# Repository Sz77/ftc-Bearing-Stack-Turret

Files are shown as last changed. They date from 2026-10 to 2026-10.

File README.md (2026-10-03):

# Bearing Stack Turret with Vernier Encoder (BETA)

Designed by **Stefan** 
*Alum of FRC 5654 (Phoenix) | Mentor for FTC 12201 (TATOOINE)*

> **⚠️ STATUS: BETA & UNTESTED**
> I designed this setup for fun. It is currently in Beta and has not been fully tested yet. Feel free to copy, use, and learn from it, but please provide credit if you use or adapt this design!

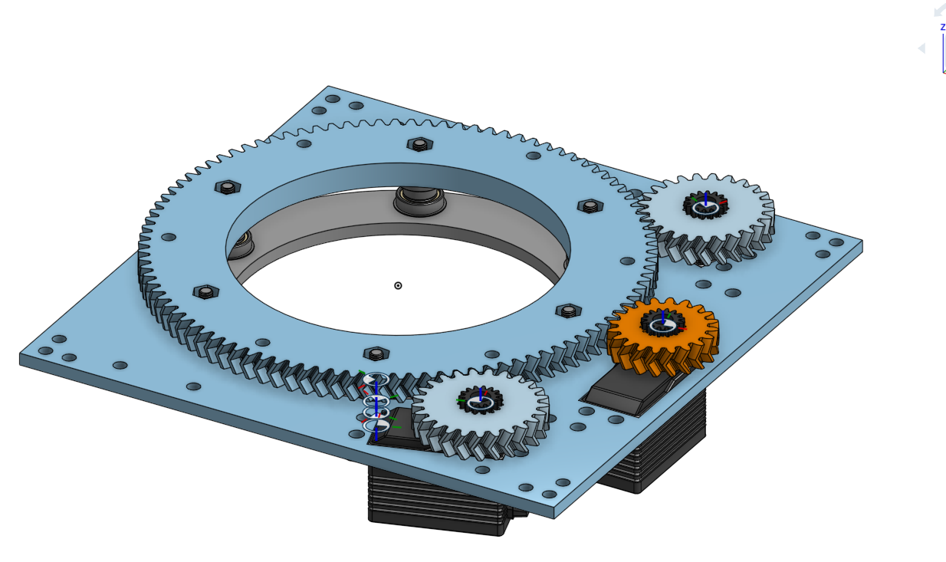
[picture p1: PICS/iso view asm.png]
Isometric View Assembly

*(TODO: Place a picture of the fully assembled physical turret here)*

## CAD & Files Availability
I will not publish the native CAD (at least not anytime soon). However, I do publish the **STLs, DXFs, and example code** here for you to use. Sometime in the future, I will publish the Onshape document.

### Repository Structure
* **`STL/`** - Contains all the 3D printable STL files (like the bearing adapters).
* **`DXF/`** - Contains the DXF files for machining/cutting the main plate and inner brace.
* **`code/`** - Contains the example code for reading the encoders and controlling the turret.
* **`PICS/`** - Reference images and CAD renders.

## Overview
This is a custom Bearing Stack Turret featuring a vernier encoder setup. 

**Top View:**
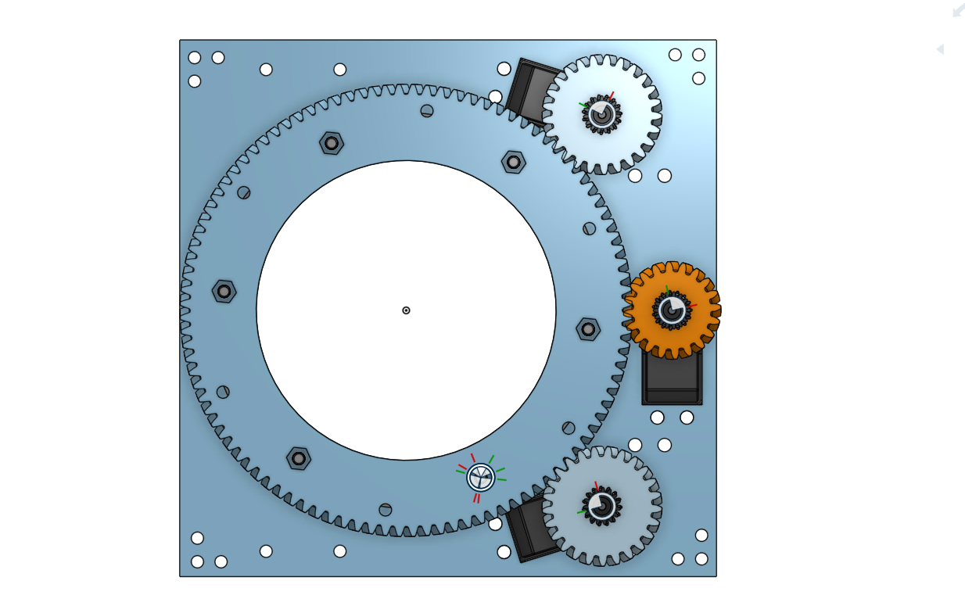
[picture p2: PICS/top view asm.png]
Turret Top View CAD


**Bottom View:**
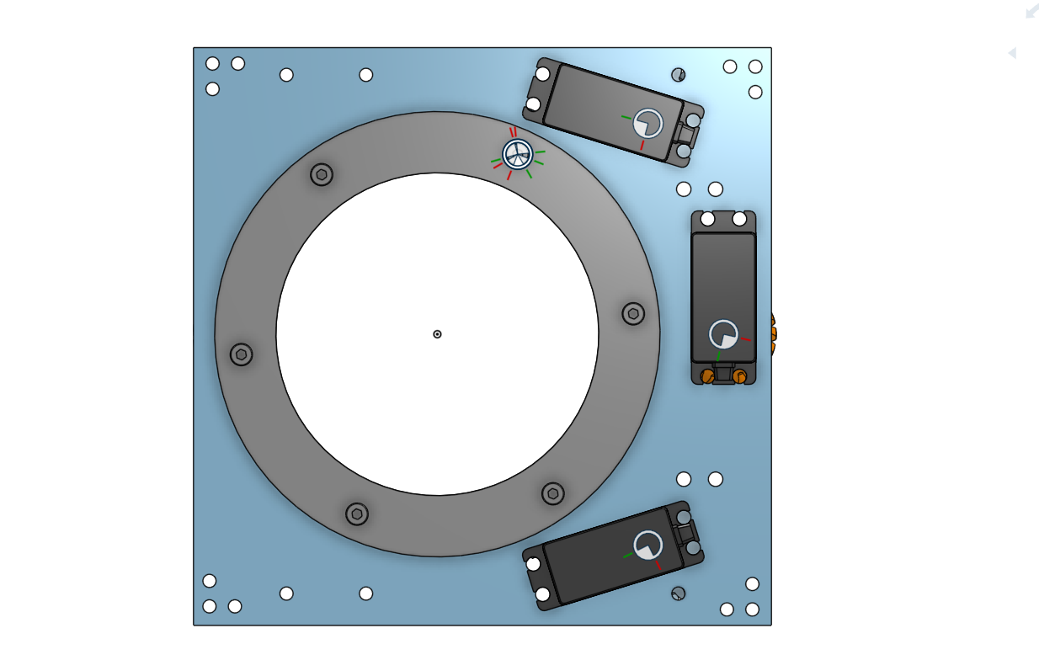
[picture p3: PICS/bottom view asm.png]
Turret Bottom View CAD


### How the Vernier Encoder Works
A vernier encoder setup uses two absolute encoders driven by gears with slightly different tooth counts—in this design, the motorized encoder A uses a 25-tooth gear and encoder B uses a 20-tooth gear, both interacting with the 100-tooth main gear. Because of the difference in tooth counts, the two encoders rotate at different speeds relative to each other as the main turret turns. By measuring the mathematical difference (or phase shift) between the readings of these two encoders, the software can calculate the exact absolute position of the main turret. This allows you to get highly precise, absolute positioning over multiple rotations without needing to mount a massive, expensive hollow-bore absolute encoder directly to the center of the turret.

---

## Bill of Materials (BOM) & Visual Part List

Below is a complete list of required parts with their CAD references. *(TODO: Add physical pictures of manufactured parts as they are made).*

### Electronics & Motors
* **1 or 2x Axon MINI Servos:** Used for turret rotation. With an Axon MINI, the max turret RPM is ~27.
  * *(TODO: Physical Part Image - Axon MINI)*
* **1x Axon MAX or Axon MINI (for Encoder B):** 
  * 🛑 **CRITICAL WARNING:** This is used *strictly* for its encoder. **DO NOT plug in the PWM cable.** Only plug in the analog sensor.
  * *(TODO: Physical Part Image - Axon MAX/MINI)*

### Gears
* **1x Main Gear:** 100 Teeth
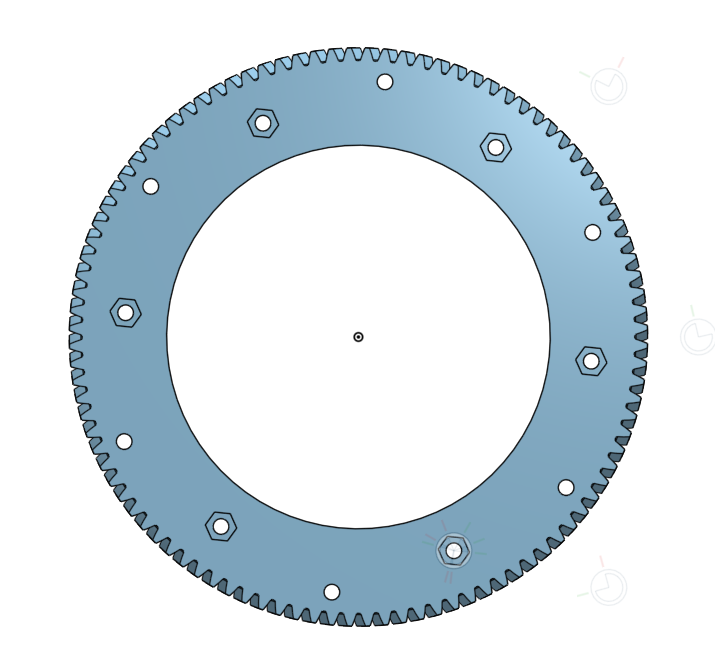
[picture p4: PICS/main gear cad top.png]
Main Gear CAD
  * 
* **1 or 2x Encoder A Gear (Motorized):** 25 Teeth 
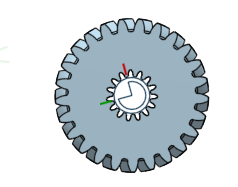
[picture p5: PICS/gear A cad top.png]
Gear A CAD
  * 
* **1x Encoder B Gear:** 20 Teeth
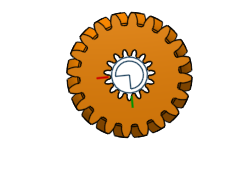
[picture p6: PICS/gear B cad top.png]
Gear B CAD
  * 
* **2 or 3x Servo Gears (15T Gear to 25T Spline):** 
  * *(TODO: CAD/Physical Image - Servo Gear)*
  * *Builder's Note:* My current printed version requires disassembling the servo and heat-pressing the adapter. This is bad and I don't recommend it. Instead, I highly recommend using COTS alternatives like **REV-41-1364-PK4** or **goBILDA 2305-0025-0015**.

### Bearing Stacks (Hardware)
You will need **6 bearing stacks** in total (4 will technically work, but 6 is highly recommended). 

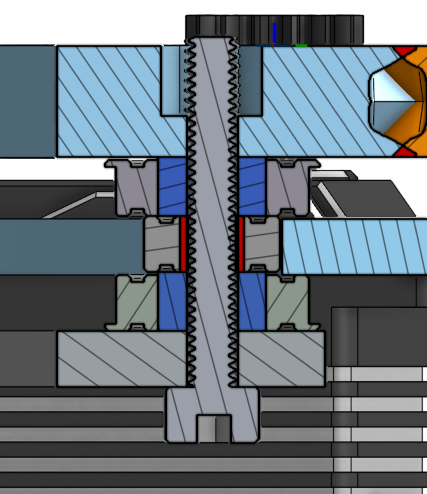
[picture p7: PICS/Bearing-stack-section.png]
Bearing Stack Section View


**For EACH of the 6 stacks, you need:**
* **2x Big Bearings:** Standard round goBILDA bearings.
* **2x Printed Adapters:** 4mm screw to 8mm goBILDA ID.
* **1x Small Bearing:** 4x10x4mm
* **1x M4 Screw & Nut:** Nylock nuts highly recommended.

### Structural Plates & Materials
* **Main Plate:** 6061 Aluminum is highly recommended. (Polycarbonate might work, but advised against).
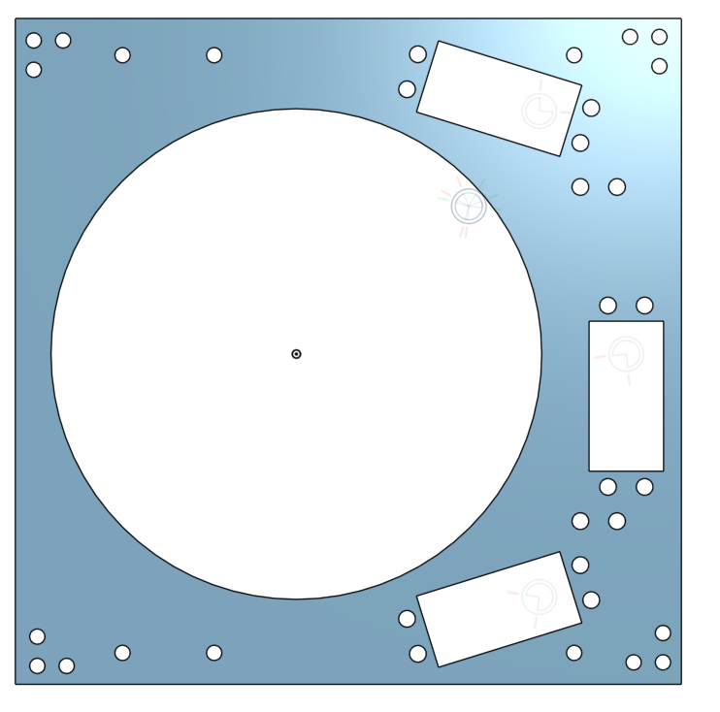
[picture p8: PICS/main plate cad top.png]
Main Plate CAD
  * 
* **Inner Brace:** Polycarbonate works well.
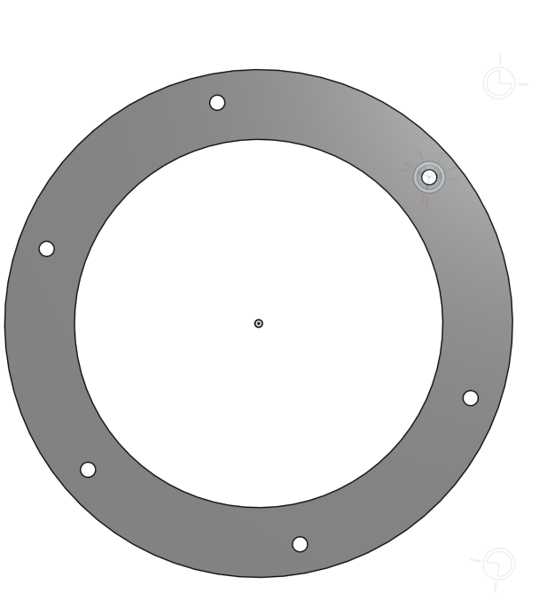
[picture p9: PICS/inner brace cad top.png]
Inner Brace CAD
  * 

---

## Assembly Guide

### Step-by-Step (Lego-Style) Instructions

**Step 1: Bearing Stack Pre-Assembly**
* Assemble the 6 bearing stacks using the big bearings, small bearing, printed adapters, and M4 hardware. Ensure Nylock nuts are secure but allow the bearings to spin freely.
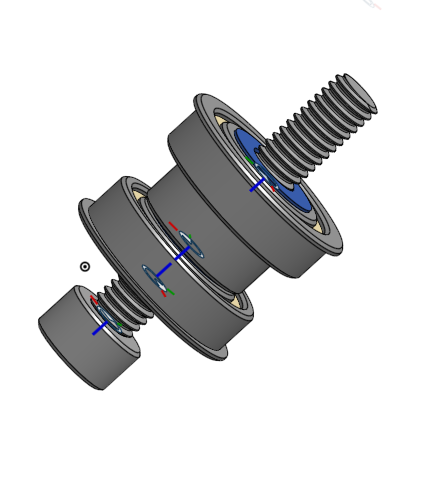
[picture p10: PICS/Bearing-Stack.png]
Bearing Stack
* 
* *(TODO: Physical assembly step picture)*

**Step 2: Installing Stacks to the Inner Brace**
* Mount the assembled bearing stacks onto the inner brace. 
* *(Reference `inner brace cad top.png` and `bottom view asm.png` for layout)*
* *(TODO: Physical assembly step picture)*

**Step 3: Main Plate & Gear Alignment**
* Sandwich the main 100T gear and fit the main plate over the bearing stacks. Double-check that the turret rotates smoothly without binding.
* *(Reference `iso view asm.png` for stacking order)*
* *(TODO: Physical assembly step picture)*

**Step 4: Servo & Vernier Encoder Mounting**
* Mount the 1 or 2 Axon MINIs (with 25T Gear A) and the passive Axon MAX/MINI (with 20T Gear B). 
* Carefully align the gear mesh before fully tightening the mounting screws to prevent stripping the teeth under load.
* *(Reference `top view asm.png` for gear positions)*
* *(TODO: Physical assembly step picture)*

**Step 5: Final Wiring & Verification**
* Route the servo cables. Remember to ONLY plug in the analog sensor cable for the Encoder B servo.
* *(TODO: Physical wiring/verification step picture)*

## License & Usage
Made for the robotics community. You are welcome to copy, use, and learn from this design. Please credit Stefan / FRC 5654 / FTC 12201 when sharing or implementing.

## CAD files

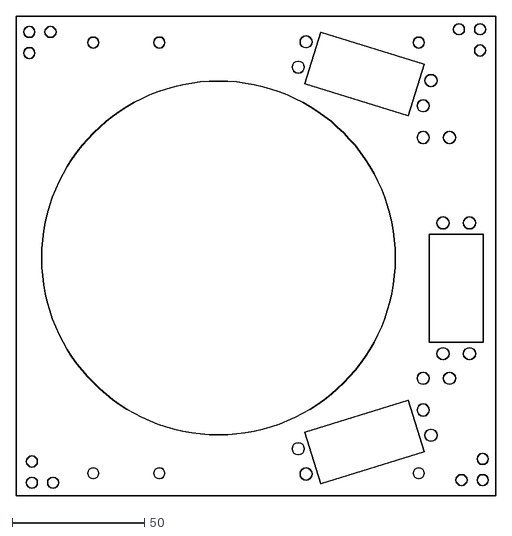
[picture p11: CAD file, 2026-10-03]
DXF/main plate-4mm-top.dxf
181.6 x 181.6

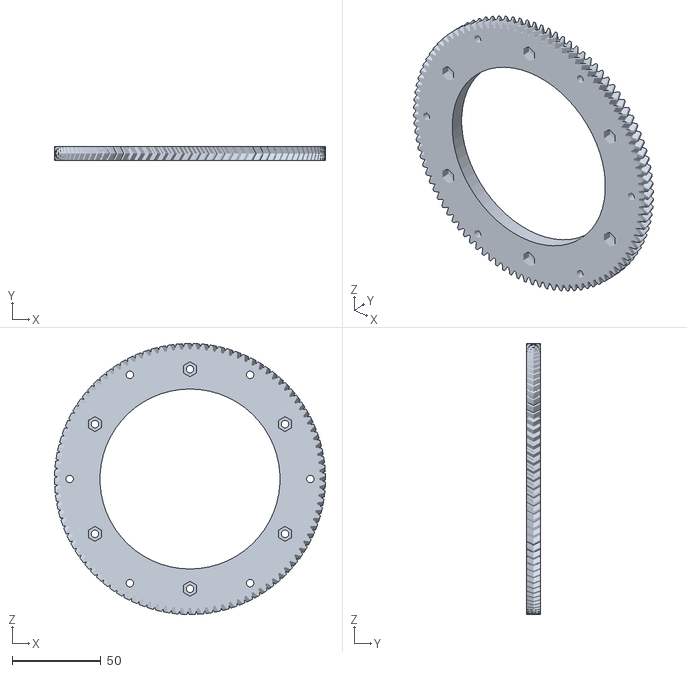
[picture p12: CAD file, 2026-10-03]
STL/main gear 100T.stl
153.0 x 8.00 x 153.0

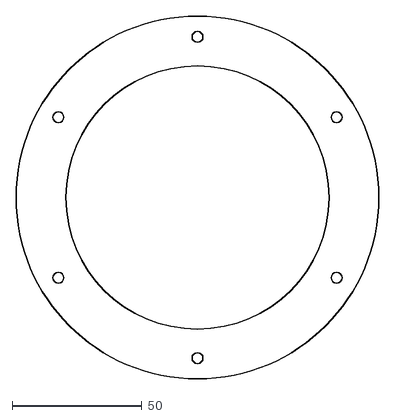
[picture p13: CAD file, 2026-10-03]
DXF/inner brace -4mm-top.dxf
140.0 x 140.0

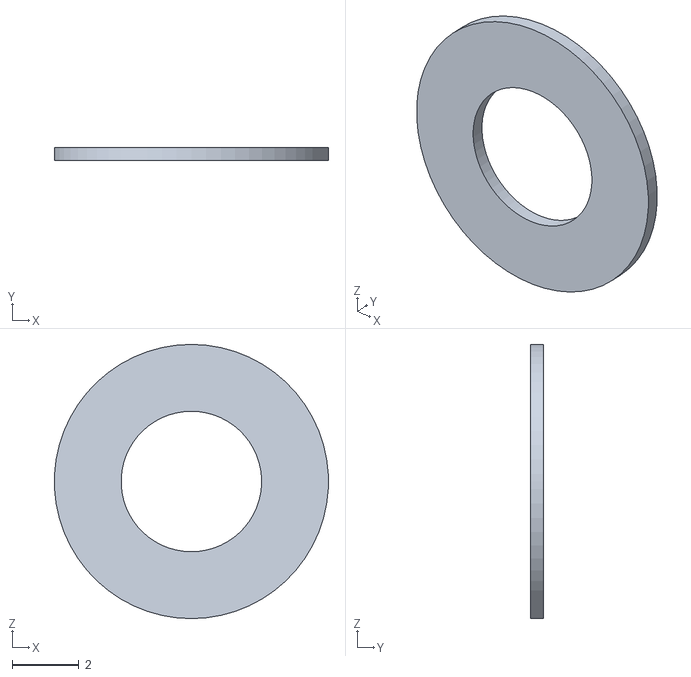
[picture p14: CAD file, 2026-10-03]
STL/Bearing stack spacer (put between the bearing and the plates).stl
8.19 x 0.4 x 8.20

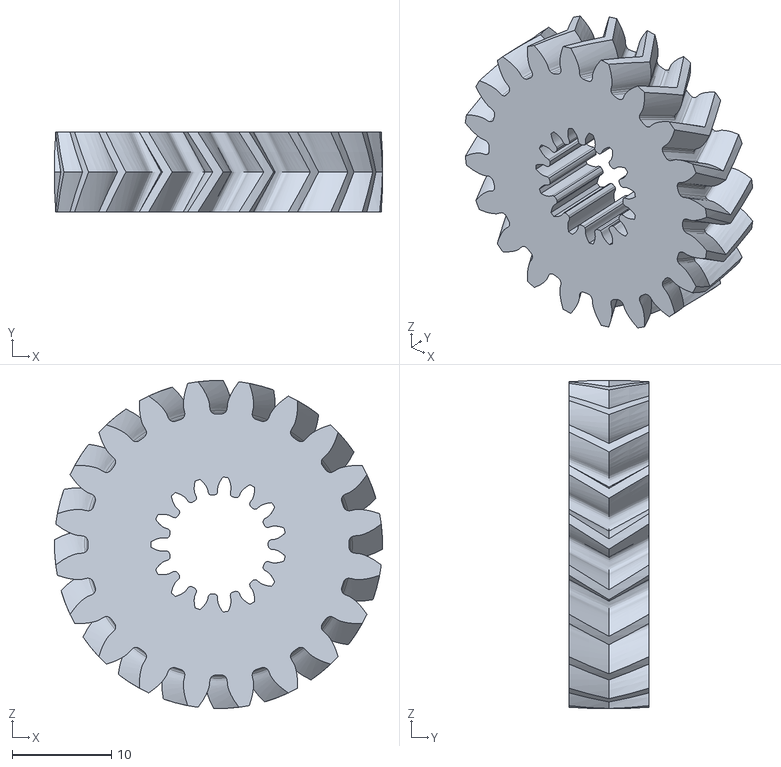
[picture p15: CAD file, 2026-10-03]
STL/gear B 20T.stl
33.0 x 8.00 x 33.0

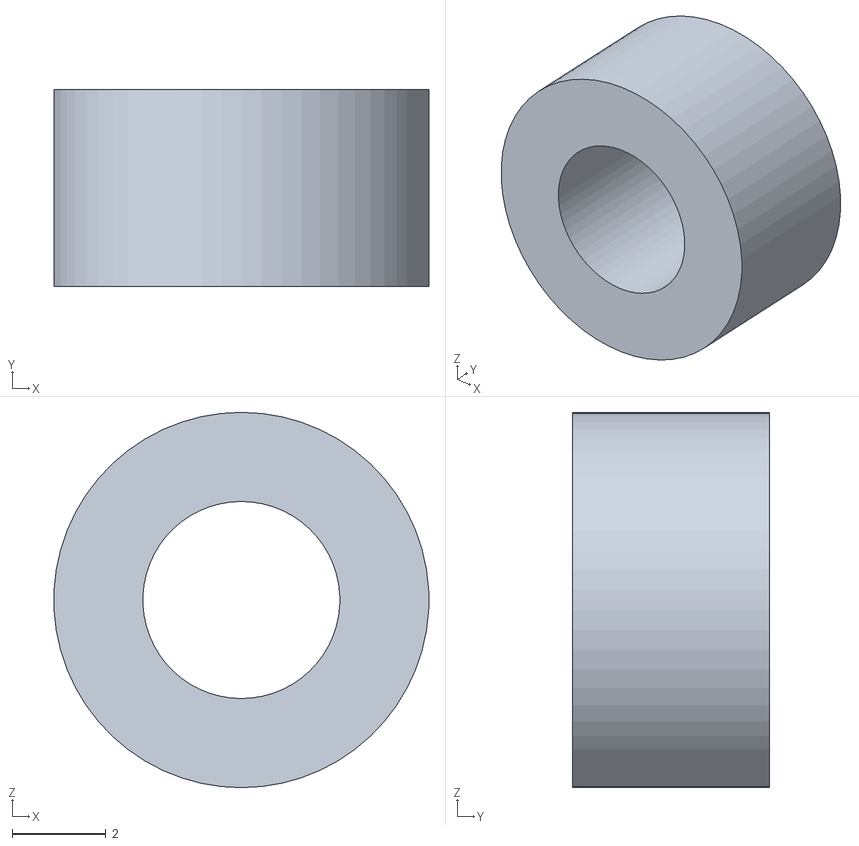
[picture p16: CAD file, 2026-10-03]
STL/4mm to 8mm adpter.stl
7.99 x 4.20 x 8.00

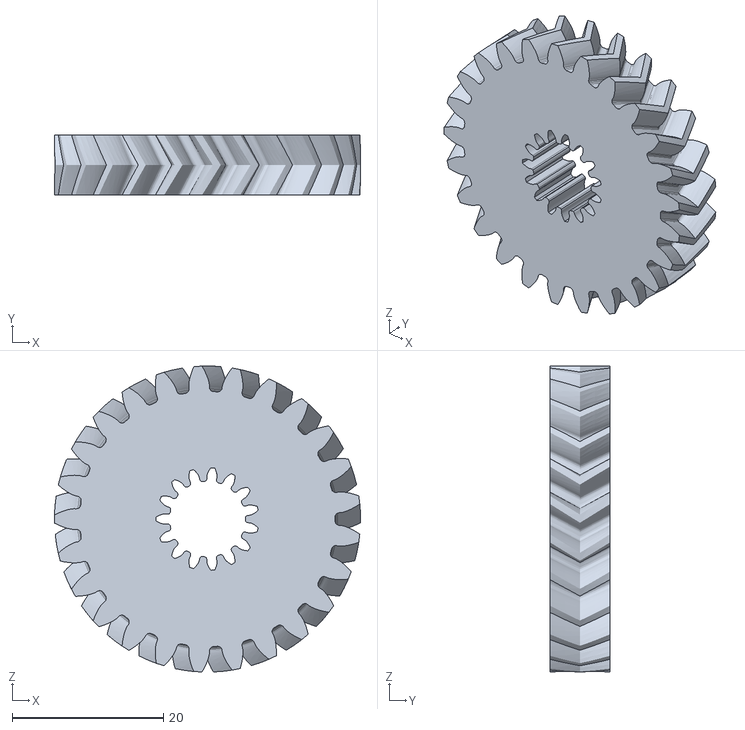
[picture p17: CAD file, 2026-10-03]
STL/gear A 25T.stl
40.5 x 8.00 x 40.5

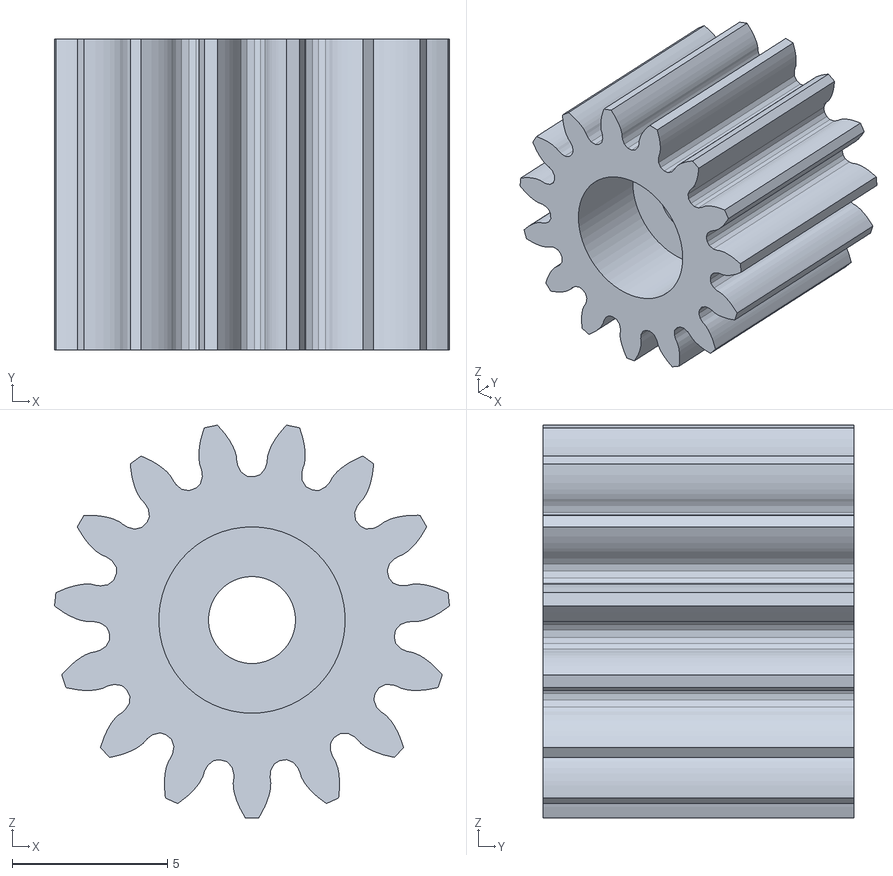
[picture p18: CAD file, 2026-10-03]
STL/Servo Gear Adapter -heatpress.stl
12.7 x 10.0 x 12.6

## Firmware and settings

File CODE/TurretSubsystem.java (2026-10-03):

package org.firstinspires.ftc.teamcode;

import com.qualcomm.robotcore.hardware.AnalogInput;
import com.qualcomm.robotcore.hardware.CRServo;
import com.qualcomm.robotcore.hardware.DcMotorSimple;
import com.qualcomm.robotcore.hardware.HardwareMap;
import com.qualcomm.robotcore.util.ElapsedTime;
import org.firstinspires.ftc.robotcore.external.Telemetry;

public class TurretSubsystem {

    // --- HARDWARE CONFIG NAMES ---
    private static final String NAME_SERVO_A1 = "servoA1";
    private static final String NAME_SERVO_A2 = "servoA2";
    private static final String NAME_ENCODER_A1 = "encoderA1";
    private static final String NAME_ENCODER_A2 = "encoderA2";
    private static final String NAME_ENCODER_B = "encoderB";

    // --- POLARITY / INVERSION CONSTANTS ---
    public static final boolean INVERT_SERVO_A1 = false;
    public static final boolean INVERT_SERVO_A2 = true;

    public static final boolean INVERT_ENCODER_A1 = false;
    public static final boolean INVERT_ENCODER_A2 = false;
    public static final boolean INVERT_ENCODER_B  = false;

    // --- ENCODER MATH CONSTANTS ---
    private static final double ENCODER_MAX_VOLTAGE = 3.3;
    private static final double MAX_DEGREES = 360.0;

    // Paste the outputs from the Calibration OpMode here
    public static final double OFFSET_A1 = 0.0;
    public static final double OFFSET_A2 = 0.0;
    public static final double OFFSET_B  = 0.0;

    // --- TURRET LIMIT CONSTANTS (SOFTWARE BUMPERS) ---
    // Safely restricted to prevent reaching the physical wire limits or the 360 math wrap
    public static final double MIN_TURRET_ANGLE_DEG = 10.0;
    public static final double MAX_TURRET_ANGLE_DEG = 350.0;

    // Absolute limits: Motor power is completely cut if momentum carries it here
    public static final double HARD_STOP_BUFFER_MIN = 5.0;
    public static final double HARD_STOP_BUFFER_MAX = 355.0;

    // --- NOISE FILTER & TOLERANCE CONSTANTS ---
    public static final double FILTER_ALPHA = 0.75;
    public static final double TARGET_TOLERANCE_DEG = 1.5;

    // --- MOTOR POWER CONSTANTS ---
    private static final double MAX_SERVO_POWER = 1.0;
    private static final double MIN_SERVO_POWER = -1.0;
    private static final double STOP_POWER = 0.0;

    // --- PID CONSTANTS ---
    public static final double kP = 0.015;
    public static final double kI = 0.000;
    public static final double kD = 0.0001;
    public static final double MAX_INTEGRAL_SUM = 20.0;
    public static final double INTEGRAL_ACTIVE_ZONE_DEG = 15.0;

    private final CRServo servoA1;
    private final CRServo servoA2;
    private final AnalogInput encoderA1;
    private final AnalogInput encoderA2;
    private final AnalogInput encoderB;

    private final ElapsedTime pidTimer;
    private double lastError = 0.0;
    private double integralSum = 0.0;

    private double prevRawAngle = 0.0;
    private double unwrappedAngle = 0.0;
    private double filteredTurretAngle = 0.0;
    private boolean angleInitialized = false;

    public TurretSubsystem(HardwareMap hwMap) {
        servoA1 = hwMap.get(CRServo.class, NAME_SERVO_A1);
        servoA2 = hwMap.get(CRServo.class, NAME_SERVO_A2);

        if (INVERT_SERVO_A1) servoA1.setDirection(DcMotorSimple.Direction.REVERSE);
        if (INVERT_SERVO_A2) servoA2.setDirection(DcMotorSimple.Direction.REVERSE);

        encoderA1 = hwMap.get(AnalogInput.class, NAME_ENCODER_A1);
        encoderA2 = hwMap.get(AnalogInput.class, NAME_ENCODER_A2);
        encoderB = hwMap.get(AnalogInput.class, NAME_ENCODER_B);

        pidTimer = new ElapsedTime();
    }

    private double trueModulo(double value, double mod) {
        return ((value % mod) + mod) % mod;
    }

    private double getNormalizedAngle(AnalogInput encoder, double offset, boolean invert) {
        double rawDeg = (encoder.getVoltage() / ENCODER_MAX_VOLTAGE) * MAX_DEGREES;
        if (invert) {
            rawDeg = MAX_DEGREES - rawDeg;
        }
        return trueModulo(rawDeg - offset, MAX_DEGREES);
    }

    private double getAverageAngleA() {
        double a1 = Math.toRadians(getNormalizedAngle(encoderA1, OFFSET_A1, INVERT_ENCODER_A1));
        double a2 = Math.toRadians(getNormalizedAngle(encoderA2, OFFSET_A2, INVERT_ENCODER_A2));

        double x = Math.cos(a1) + Math.cos(a2);
        double y = Math.sin(a1) + Math.sin(a2);

        double avgDeg = Math.toDegrees(Math.atan2(y, x));
        return trueModulo(avgDeg, MAX_DEGREES);
    }

    /**
     * Reads hardware sensors, unwraps, and applies filters.
     * MUST be called exactly once per loop in the OpMode.
     */
    public void readSensors() {
        double angleB = getNormalizedAngle(encoderB, OFFSET_B, INVERT_ENCODER_B);
        double avgAngleA = getAverageAngleA();

        double rawTurret = trueModulo(angleB - avgAngleA, MAX_DEGREES);

        if (!angleInitialized) {
            prevRawAngle = rawTurret;
            unwrappedAngle = rawTurret;
            filteredTurretAngle = rawTurret;
            angleInitialized = true;
        } else {
            double delta = rawTurret - prevRawAngle;

            if (delta > 180.0) delta -= MAX_DEGREES;
            else if (delta < -180.0) delta += MAX_DEGREES;

            unwrappedAngle += delta;
            prevRawAngle = rawTurret;
        }

        filteredTurretAngle = (FILTER_ALPHA * unwrappedAngle) + ((1.0 - FILTER_ALPHA) * filteredTurretAngle);
    }

    /**
     * Pure getter for the turret angle. Does not mutate state or trigger hardware reads.
     */
    public double getTurretAngle() {
        return filteredTurretAngle;
    }

    public void setTargetAngle(double targetAngle) {
        // Enforce the safe Software Bumpers
        targetAngle = Math.max(MIN_TURRET_ANGLE_DEG, Math.min(MAX_TURRET_ANGLE_DEG, targetAngle));

        double currentAngle = getTurretAngle();
        double error = targetAngle - currentAngle;

        double dt = pidTimer.seconds();
        pidTimer.reset();

        if (Math.abs(error) <= TARGET_TOLERANCE_DEG) {
            servoA1.setPower(STOP_POWER);
            servoA2.setPower(STOP_POWER);
            integralSum = 0;
            lastError = error;
            return;
        }

        if (Math.abs(error) < INTEGRAL_ACTIVE_ZONE_DEG) {
            integralSum += (error * dt);
            integralSum = Math.max(-MAX_INTEGRAL_SUM, Math.min(MAX_INTEGRAL_SUM, integralSum));
        } else {
            integralSum = 0;
        }

        double derivative = 0;
        if (dt > 0.005) {
            derivative = (error - lastError) / dt;
        }
        lastError = error;

        double power = (kP * error) + (kI * integralSum) + (kD * derivative);
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

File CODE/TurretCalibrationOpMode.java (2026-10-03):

package org.firstinspires.ftc.teamcode;

import com.qualcomm.robotcore.eventloop.opmode.LinearOpMode;
import com.qualcomm.robotcore.eventloop.opmode.TeleOp;
import com.qualcomm.robotcore.hardware.Gamepad;

@TeleOp(name = "Turret Calibration & Testing", group = "Testing")
public class TurretCalibrationOpMode extends LinearOpMode {

    private enum State {
        SERVO_TEST,
        ENCODER_POLARITY_TEST,
        OFFSET_CAPTURE,
        MANUAL_SWEEP
    }

    @Override
    public void runOpMode() {
        TurretSubsystem turret = new TurretSubsystem(hardwareMap);
        State currentState = State.SERVO_TEST;

        double capturedOffsetA1 = 0.0;
        double capturedOffsetA2 = 0.0;
        double capturedOffsetB = 0.0;

        double maxSweepAngle = 180.0;
        double minSweepAngle = 180.0;

        Gamepad currentGamepad1 = new Gamepad();
        Gamepad previousGamepad1 = new Gamepad();

        turret.readSensors(); // Initialize filter states before loop

        telemetry.addLine("Turret Calibration OpMode Initialized.");
        telemetry.addLine("WARNING: Keep turret within safe wire boundaries!");
        telemetry.addLine("Press START to begin.");
        telemetry.update();

        waitForStart();

        while (opModeIsActive()) {
            previousGamepad1.copy(currentGamepad1);
            currentGamepad1.copy(gamepad1);

            // Run exactly once per loop to continuously track wrap-arounds regardless of state
            turret.readSensors();

            switch (currentState) {

                case SERVO_TEST:
                    telemetry.addLine("--- STEP 1: SERVO DIRECTION ---");
                    telemetry.addLine("Push BOTH sticks UP. The turret MUST spin in the SAME direction.");
                    telemetry.addLine("If they fight, flip INVERT_SERVO_A2 in Subsystem.");
                    telemetry.addLine("Press 'A' to move to next step.");

                    turret.setRawMotorPowerA1(-currentGamepad1.left_stick_y);
                    turret.setRawMotorPowerA2(-currentGamepad1.right_stick_y);

                    if (currentGamepad1.a && !previousGamepad1.a) {
                        turret.stopMotors();
                        currentState = State.ENCODER_POLARITY_TEST;
                    }
                    break;

                case ENCODER_POLARITY_TEST:
                    turret.stopMotors();
                    telemetry.addLine("--- STEP 2: ENCODER POLARITY ---");
                    telemetry.addLine("Turn the turret slowly by hand to the RIGHT.");
                    telemetry.addLine("ALL THREE numbers below should INCREASE.");
                    telemetry.addLine("If one decreases, change its INVERT_ENCODER const to true.");
                    telemetry.addLine("");
                    telemetry.addData("Raw A1", "%.2f", turret.getRawDegreeA1());
                    telemetry.addData("Raw A2", "%.2f", turret.getRawDegreeA2());
                    telemetry.addData("Raw B", "%.2f", turret.getRawDegreeB());
                    telemetry.addLine("");
                    telemetry.addLine("Press 'B' when all 3 increase together.");

                    if (currentGamepad1.b && !previousGamepad1.b) {
                        currentState = State.OFFSET_CAPTURE;
                    }
                    break;

                case OFFSET_CAPTURE:
                    turret.stopMotors();
                    telemetry.addLine("--- STEP 3: CAPTURE ZERO OFFSETS ---");
                    telemetry.addLine("Push the turret to the safest leftmost physical limit you want as '0'.");
                    telemetry.addLine("DO NOT wrap the wires!");
                    telemetry.addLine("Hold it, then press 'X' to capture offsets.");
                    telemetry.addLine("");
                    telemetry.addData("Live Raw A1", "%.2f", turret.getRawDegreeA1());
                    telemetry.addData("Live Raw A2", "%.2f", turret.getRawDegreeA2());
                    telemetry.addData("Live Raw B", "%.2f", turret.getRawDegreeB());

                    if (currentGamepad1.x && !previousGamepad1.x) {
                        capturedOffsetA1 = TurretSubsystem.INVERT_ENCODER_A1 ? (360.0 - turret.getRawDegreeA1()) : turret.getRawDegreeA1();
                        capturedOffsetA2 = TurretSubsystem.INVERT_ENCODER_A2 ? (360.0 - turret.getRawDegreeA2()) : turret.getRawDegreeA2();
                        capturedOffsetB  = TurretSubsystem.INVERT_ENCODER_B ? (360.0 - turret.getRawDegreeB()) : turret.getRawDegreeB();

                        // Seed max/min sweep bounds to current angle
                        maxSweepAngle = turret.getTurretAngle();
                        minSweepAngle = maxSweepAngle;

                        currentState = State.MANUAL_SWEEP;
                    }
                    break;

                case MANUAL_SWEEP:
                    turret.stopMotors();
                    double currentCalculatedAngle = turret.getTurretAngle();

                    if (currentCalculatedAngle > maxSweepAngle) maxSweepAngle = currentCalculatedAngle;
                    if (currentCalculatedAngle < minSweepAngle) minSweepAngle = currentCalculatedAngle;

                    telemetry.addLine("--- STEP 4: MANUAL SWEEP VERIFICATION ---");
                    telemetry.addLine("Sweep the turret back and forth within wire limits.");
                    telemetry.addLine("Check for smooth counting without random jumps.");
                    telemetry.addLine("");
                    telemetry.addData("Calculated Angle", "%.2f deg", currentCalculatedAngle);
                    telemetry.addData("Observed Min Angle", "%.2f deg", minSweepAngle);
                    telemetry.addData("Observed Max Angle", "%.2f deg", maxSweepAngle);
                    telemetry.addLine("");
                    telemetry.addLine("--- COPY THESE INTO TURRETSUBSYSTEM.JAVA ---");
                    telemetry.addData("OFFSET_A1", "%.2f", capturedOffsetA1);
                    telemetry.addData("OFFSET_A2", "%.2f", capturedOffsetA2);
                    telemetry.addData("OFFSET_B", "%.2f", capturedOffsetB);
                    break;
            }

            telemetry.update();
        }
    }
}

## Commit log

2026-10-03 Enhance README with design and assembly details
    Expanded the README to include detailed design information, assembly instructions, and a bill of materials for the Bearing Stack Turret with Vernier Encoder.
2026-10-03 bata v1 ready
    [4mm to 8mm adpter.stl, Servo Gear Adapter -heatpress.stl, gear A 25T.stl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]
2026-10-03 Bearing stack spacer (put between the bearing and the plates)
    [Bearing stack spacer (put between the bearing and the plates).stl]
2026-10-03 Refactor TurretSubsystem to fix state mutation, loop-time drops, and startup hazards
    [TurretCalibrationOpMode.java, TurretSubsystem.java]
